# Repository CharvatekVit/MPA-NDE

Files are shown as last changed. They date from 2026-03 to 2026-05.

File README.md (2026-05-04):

# Jet ADCS with Siphon Cartridge

Experimental Attitude Determination and Control System (ADCS) for CubeSats using a reaction-based pneumatic propulsion system (RPPS).

---

Team members

1. Vít Charvátek (responsible for Pneumatics)
2. Vít Janoš (responsible for Electronics)
4. Antonín Putala (responsible for Software, Structure)

> [!WARNING]
> May 5 will be final presentation.

## 1. Project Overview
The **Jet ADCS with Siphon Cartridge** is an engineering project focused on the design and implementation of a single-axis orientation control system for nanosatellites (CubeSats). While traditional CubeSats rely on reaction wheels or magnetorquers, this project explores the use of compressed air to generate torque.

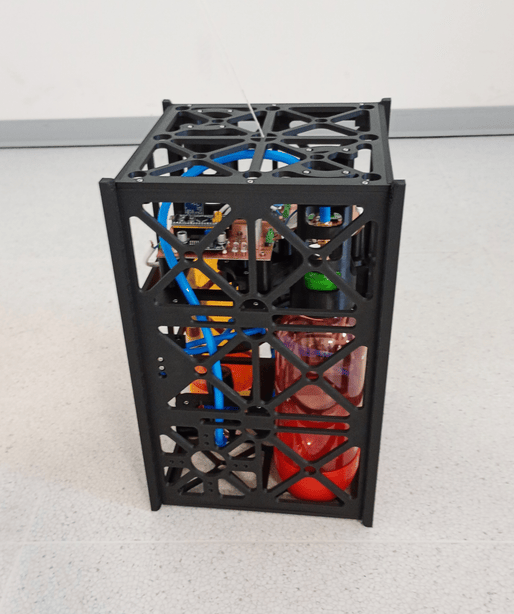
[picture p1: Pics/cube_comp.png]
Finished cube
 

### Core Concept
The system uses a compressed air as a propellant source. By regulating the pressure and precisely timing the opening of solenoid valves, the system can produce controlled thrust through two nozzles. This thrust creates a mechanical moment that allows the satellite to rotate to a desired angular position or maintain stability.

## Requirements
1.	Operation on battery supply
2.	Wireless control capability
2.  Attitude determination using an onboard sensor
2.  Actuation using compressed air
2.	Analysis of the pulse response of the system
2.  Maintaining a stable orientation around a single axis
2.	Performing controlled orientation changes

### Conceptual Scheme
The operational logic follows this flow:
1. **Sensing:** The IMU tracks the current orientation and angular velocity.
2. **Processing:** The STM32 microcontroller calculates the error between the desired and current state via a PID algorithm.
3. **Actuation:** Solenoid valves release precise bursts of air through nozzles to correct the orientation.
4. **Monitoring:** Data is sent wirelessly via Bluetooth to a ground station for real-time analysis.

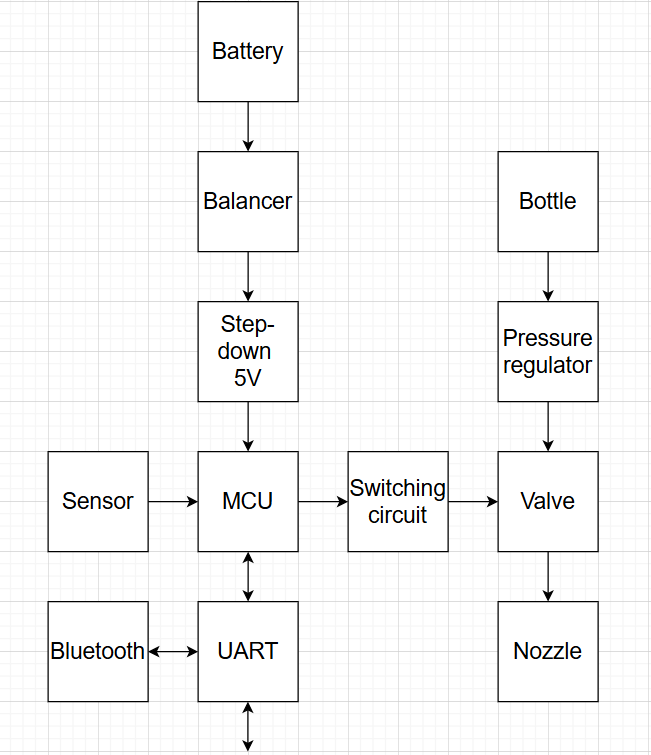
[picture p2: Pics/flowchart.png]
Conceptual diagram


---

## 2. Electronics
The electronics subsystem provides the "intelligence" and power management for the device.
* **Control Unit:** STM32 "Blue Pill" (ARM Cortex-M3) managing high-speed PID loops and valve timing.
* **Sensors:** MPU9250 (9-axis IMU) providing high-precision data via SPI.
* **Communication:** HC-05 Bluetooth module for wireless telemetry and command uplink.
* **Power:** 3x Li-ion 18650 cells with an integrated BMS (Battery Management System) and a DC/DC converter for a stable 5V rail.

---

## 3. Pneumatics
The propulsion system is designed for reliability and simplicity under terrestrial testing conditions.
* **Propellant:** Standard SodaStream bottle with compressed air.
* **Regulation:** AR2000 pressure regulator to step down high cartridge pressure to a constant operational level.
* **Actuators:** Two 2V025-08 electromagnetic solenoid valves.

---

## 4. Structure
The mechanical frame follows the CubeSat form factor philosophy, optimized for a single-axis testbed.
* **Frame:** 12U-inspired vertical structure manufactured using PETG filament on a 3D printer.
* **Assembly:** Secured with M2.5 threaded heat-set inserts for high durability and repeatable maintenance.
* **Balancing:** Adjustable mounts for internal components to align the center of mass with the rotation axis.

---

## 5. Software
The firmware is written in C, focusing on low latency and deterministic control.
* **Control Loop:** An easy function enables perform motion commands.
* **Data Fusion:** Processing of gyroscope data from the MPU9250.
* **Interface:** Custom serial protocol over Bluetooth for real-time controlling and state monitoring.

---

## Task list
- [x] System
   * [x] Conceptual diagram
   * [x] Requirements
   * [x] Energy budget
   * [x] Component list
   * [x] Component purchase
   * [x] Physical description
   * [x] Report
- [x]  Electronics
   * [x] Component choice 
      - [x] Battery
      - [x] Step-down
      - [x] Accelerometer
   * [x] Circuit design
      - [x] LED indicator
      - [x] Switching circuit
   * [x] PCB design
   * [x] Soldering
- [x]  Pneumatics
   * [x] Component choice 
      - [x] Valve
      - [x] T-hub
      - [x] Tube
   * [x]  Gas bottle construction
   * [x]  Completation pneumatic circuit
   * [x]  Sealing
   * [x]  Nozzles
- [x] Software
   * [x] Component choice 
       - [x] MCU
       - [x] Wireless module
   * [x] UART communication
       - [x] Sensor data
       - [x] Valve control
           * [x] Position setting
           * [x] Position regulation
       - [x] Command implementation
   * [x] Wireless communication
   * [x] Constant tuning
   * [x] Testing
   * [x] Doxygen
- [x] Structure
   * [x] Size estimation
   * [x] Structural design
   * [x] 3D print
   * [x] Assembly
     
---

## Documents
- [Part list](https://vutbr-my.sharepoint.com/:x:/r/personal/246858_vutbr_cz/Documents/MPA-NDE%20Part%20List.xlsx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)
- [Presentation 1](https://vutbr-my.sharepoint.com/:p:/r/personal/246850_vutbr_cz/_layouts/15/Doc.aspx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)
- [Presentation 2](https://vutbr-my.sharepoint.com/:p:/r/personal/246922_vutbr_cz/_layouts/15/Doc.aspx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)
- [Presentation 3](https://vutbr-my.sharepoint.com/:p:/r/personal/246922_vutbr_cz/_layouts/15/Doc.aspx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)
- [Presentation 4](https://vutbr-my.sharepoint.com/:p:/r/personal/246922_vutbr_cz/_layouts/15/Doc.aspx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)
- [Presentation 5](https://vutbr-my.sharepoint.com/:p:/r/personal/246922_vutbr_cz/_layouts/15/Doc.aspx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)
- [Presentation final](https://vutbr-my.sharepoint.com/:p:/r/personal/246922_vutbr_cz/_layouts/15/Doc.aspx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)
- [Programming documantation](https://raw.githack.com/CharvatekVit/MPA-NDE/main/Documentation/html/index.html)
- [Documentation](https://vutbr-my.sharepoint.com/:f:/g/personal/246922_vutbr_cz/IgBKQASchL7PSJfr07Y2DRViAZgop-J1y6nprSuAsayNgWo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)

## 6. Bibliography

[1] HALLIDAY, David; RESNICK, Robert and JEARL WALKER. Fundamentals of physics, 
New York: John Wiley, 1986.
ISBN: 9780470148853.

[2] -, Mass Flow Choking. Online. 2026 NASA. [cit. 2026-04-09]. Available from: https://www.grc.nasa.gov/WWW/K-12/airplane/mflchk.html

[3] POVALAČ, A., Nanosatellite Design and Electronics, Brno: Brno University of Technology, 
Faculty of electrical engineering and communications, 2021.

[4] -, CubeSat Design Specification. Online. 2026 NASA. [cit. 2026-04-11]. Available from: https://www.nasa.gov/wp-content/uploads/2018/01/cubesatdesignspecificationrev14_12022-02-09.pdf

[5] -, Heat Set Inserts . Online. 2026 Prusa 3D. [cit. 2026-04-12]. Available from: https://www.prusa3d.com/product/threaded-inserts-m2-5-standard-100-pcs/

[6] -, Solenoid Valve Specifications and Dimensions: 2V025 & 2V035 Series . Online. 2026 STC valve. [cit. 2026-04-18]. Available from: https://www.stcvalve.com/Solenoid_Valve_Specification_2V025.htm

[7] -, Regulátor tlaku s manometrem 1/4 palce AR2000 . Online. 2026 HP Control. [cit. 2026-04-18]. Available from: https://hpcontrol.cz/reduktor-regulator-1-4-cala-manometr-ar2000.html

[8] -, mpu9250 . Online. 2026 Libdriver. [cit. 2026-04-23]. Available from: https://github.com/libdriver/mpu9250

[9] Khaled Magdy, STM32 Blue Pill Pinout & Programming Guide . Online. 2026 DeepBlue Embedded. [cit. 2026-04-26]. Available from: https://deepbluembedded.com/stm32-blue-pill-pinout-programming-guide/

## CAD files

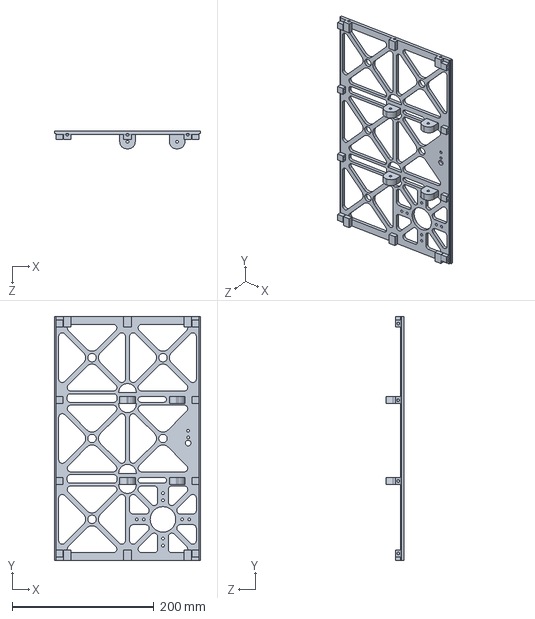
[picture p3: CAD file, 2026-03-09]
3D_model/My_side_full.SLDPRT
206.0 x 344.0 x 25.0 mm

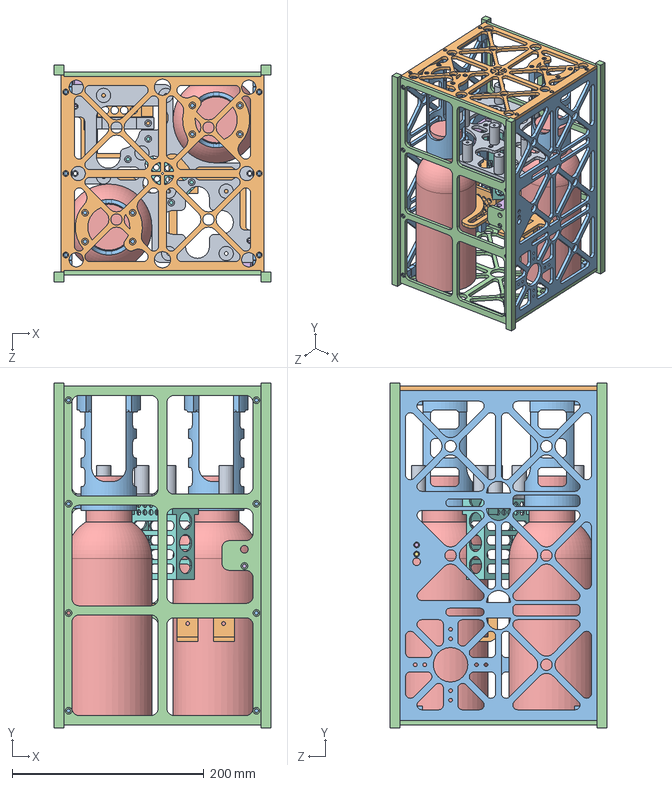
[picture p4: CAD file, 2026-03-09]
3D_model/Cube.SLDASM
226.3 x 360.0 x 226.3 mm
My_side_free x 2
My_side_full x 2
My_top
Mid_stage
Battery
Mid_tryska x 2
Top_tryska x 4
Láhev x 2
My_bottom
Drzak_lahev x 2
regulator_holder
Valve_holder

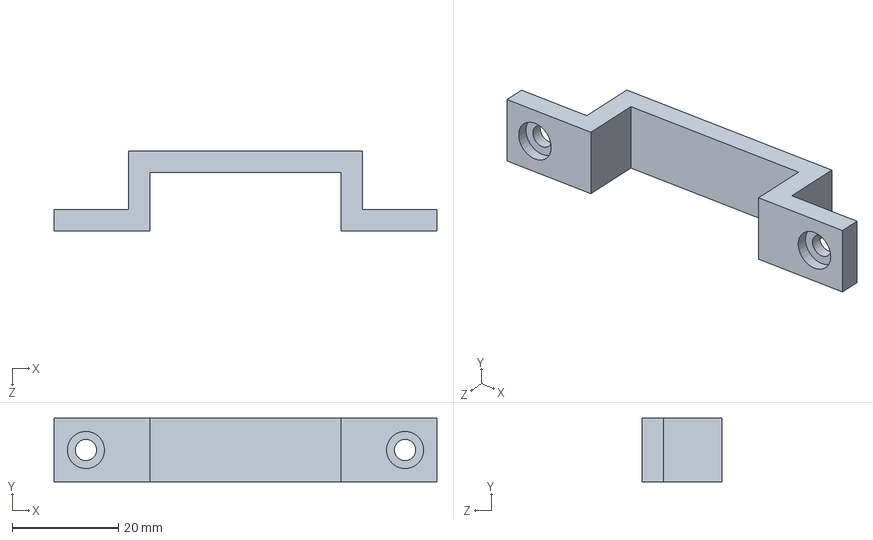
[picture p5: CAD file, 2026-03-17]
3D_model/Valve_holder.SLDPRT
72.0 x 12.0 x 15.0 mm

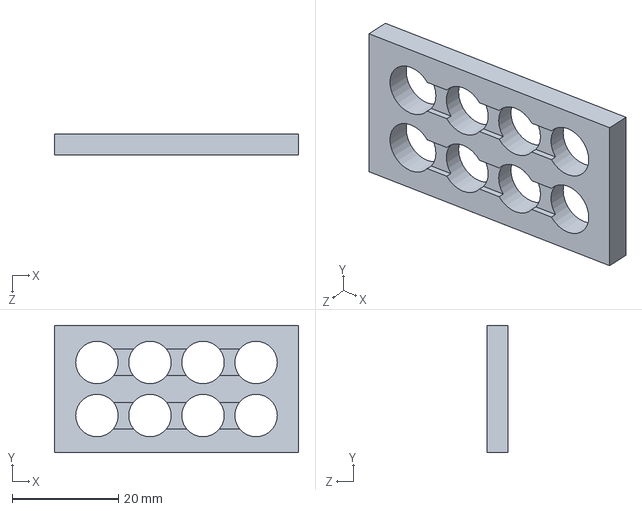
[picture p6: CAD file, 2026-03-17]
3D_model/podlozka.SLDPRT
46.0 x 24.0 x 4.00 mm

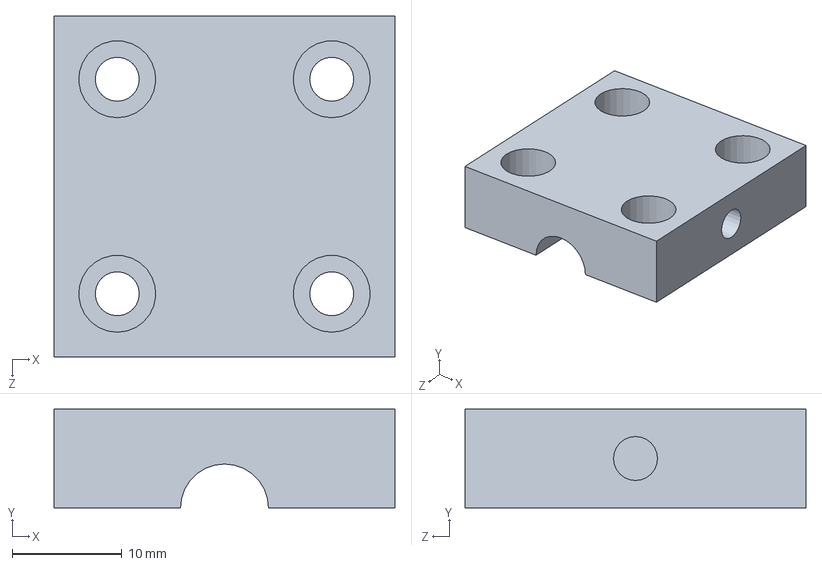
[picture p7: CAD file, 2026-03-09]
3D_model/Top_tryska.SLDPRT
31.0 x 9.00 x 31.0 mm

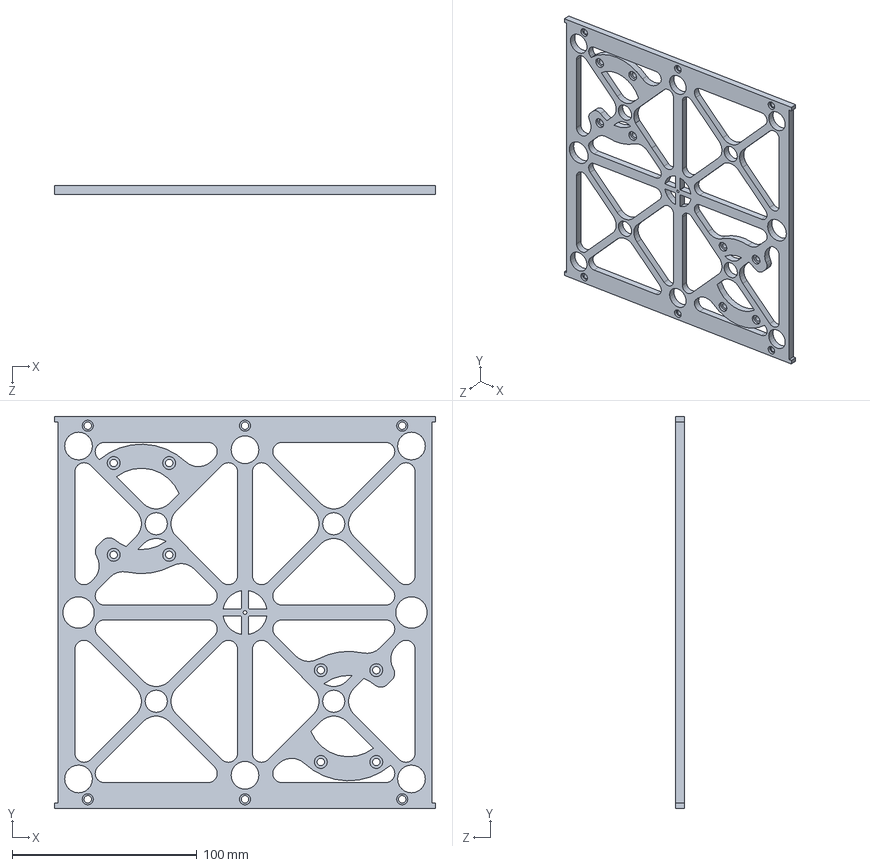
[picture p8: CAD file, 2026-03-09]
3D_model/My_top.SLDPRT
206.0 x 212.0 x 5.00 mm

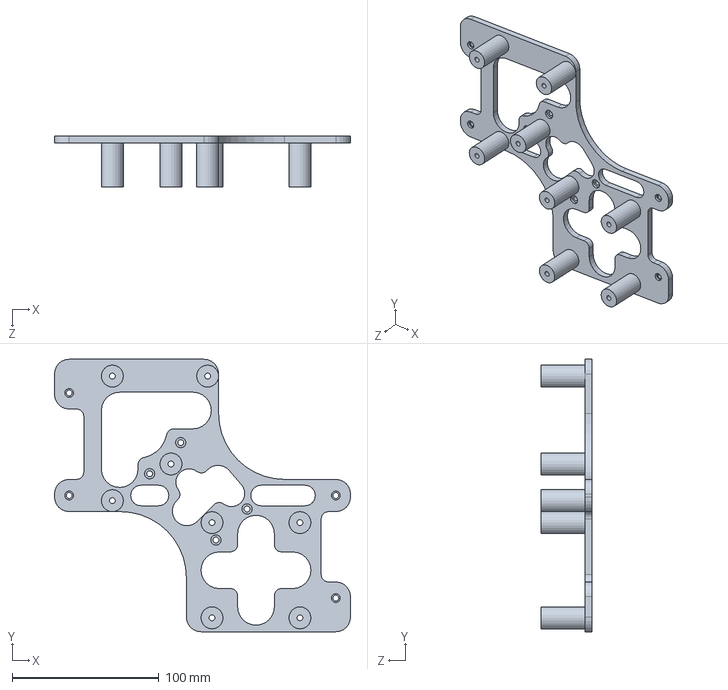
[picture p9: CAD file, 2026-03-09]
3D_model/Mid_stage.SLDPRT
202.0 x 186.0 x 35.0 mm

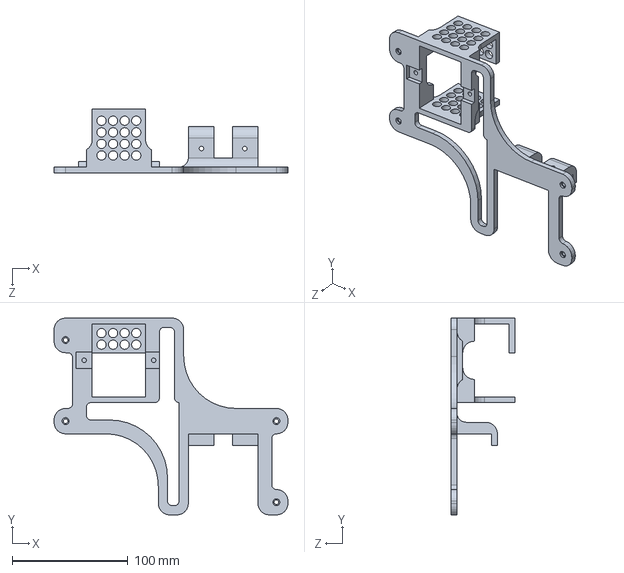
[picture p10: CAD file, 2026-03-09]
3D_model/regulator_holder.SLDPRT
202.0 x 170.0 x 55.0 mm

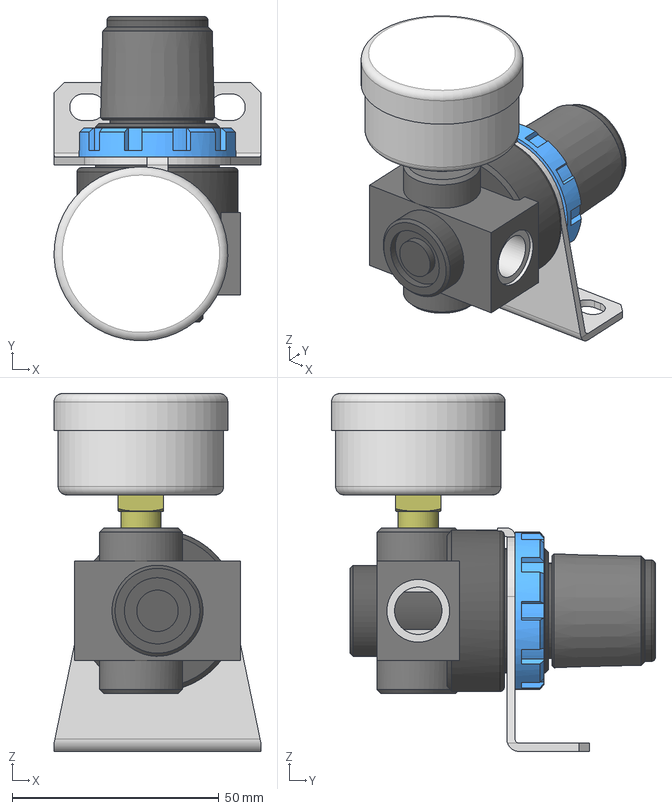
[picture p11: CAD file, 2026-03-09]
3D_model/AR2000.stp
50.0 x 78.3 x 86.5 mm
AR2000_AR
AFR2000ar_bracket
AR2000ar_nut
01gauge

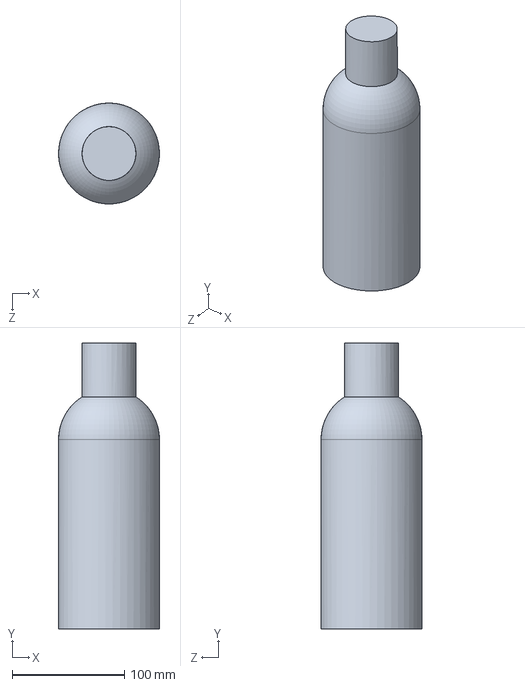
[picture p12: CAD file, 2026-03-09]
3D_model/Láhev.SLDPRT
90.0 x 255.0 x 90.0 mm

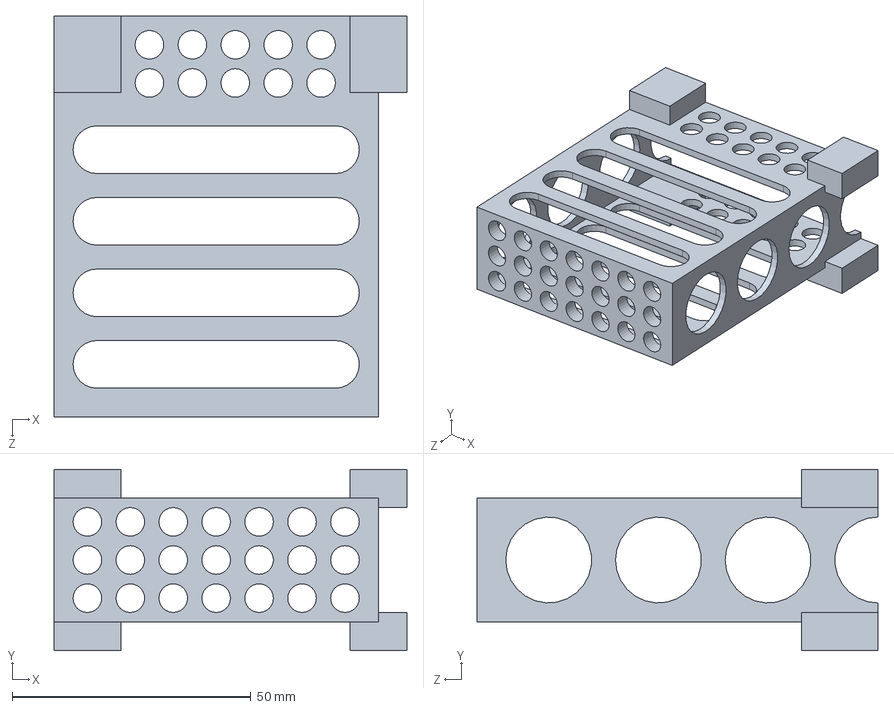
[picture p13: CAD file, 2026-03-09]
3D_model/Battery.SLDPRT
74.0 x 38.0 x 84.0 mm

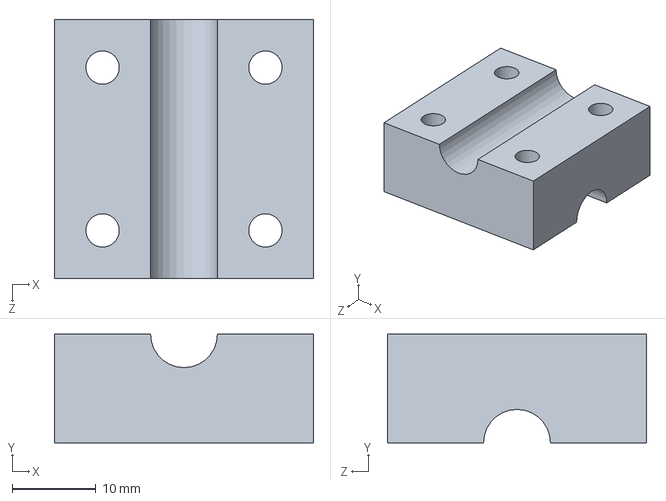
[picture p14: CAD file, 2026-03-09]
3D_model/Mid_tryska.SLDPRT
31.0 x 13.0 x 31.0 mm

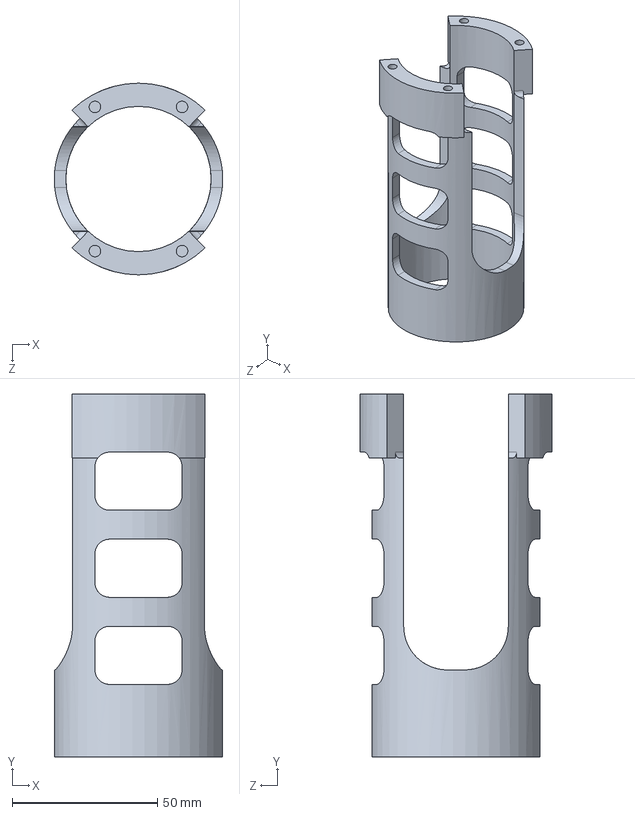
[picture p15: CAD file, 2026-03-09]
3D_model/Drzak_lahev.SLDPRT
58.0 x 125.0 x 66.0 mm

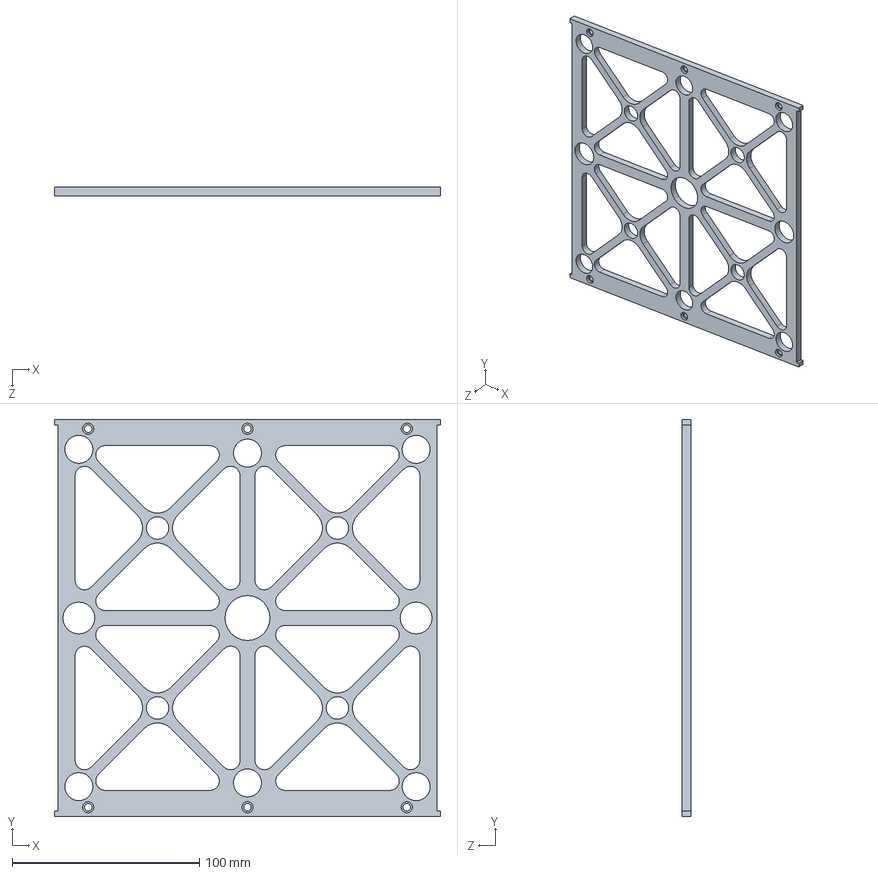
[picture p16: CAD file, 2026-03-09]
3D_model/My_bottom.SLDPRT
206.0 x 212.0 x 5.00 mm

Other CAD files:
3D_model/My_side_free.SLDPRT
3D_model/M25_10.SLDPRT

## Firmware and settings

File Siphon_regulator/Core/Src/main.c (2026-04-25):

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
/* Includes ------------------------------------------------------------------*/
#include "main.h"

/* USER CODE BEGIN Includes */
#include "cmd_processing.h"
#include "driver_mpu9250_basic.h"
#include "loop_fcn.h"
#include "sensor_fcn.h"
#include <stdio.h>
/* USER CODE END Includes */

/* USER CODE BEGIN PD */
/** Size of RX buffer for UART */
#define RX_BUFFER_LEN 64
/** Address of UART RX pointer */
#define uart_rx_write_ptr (RX_BUFFER_LEN - hdma_usart1_rx.Instance->CNDTR)

/* USER CODE END PD */

SPI_HandleTypeDef hspi2;

UART_HandleTypeDef huart1;
DMA_HandleTypeDef hdma_usart1_rx;

/* USER CODE BEGIN PV */
static uint8_t uart_rx_buf[RX_BUFFER_LEN];     ///< Received buffer fo UART
static volatile uint16_t uart_rx_read_ptr = 0; ///< Received read pointer for UART

sensor_data_t measured_data;                   ///< Current sensor measured data.
settings_t    set_data;                        ///< Main system settings.

/* USER CODE END PV */

void SystemClock_Config(void);
static void MX_GPIO_Init(void);
static void MX_DMA_Init(void);
static void MX_USART1_UART_Init(void);
static void MX_SPI2_Init(void);
/* USER CODE BEGIN PFP */

/**
 * @brief Set default values of set_data global variable.
 */
void setting_init(void);

/**
 * @brief Initialize valves. By default close.
 */
void valve_init(void);

/* USER CODE END PFP */

/* USER CODE BEGIN 0 */
int _write(int file, char const *buf, int n)
{
	/* stdout redirection to UART2 */
	HAL_UART_Transmit(&huart1, (uint8_t*)(buf), n, HAL_MAX_DELAY);
	return n;
}


void setting_init(void)
{
	/* Default data */
	set_data.angle  = 90; ///< 90 deg
	set_data.time_a = 10; ///< 10 * 0.1 = 1 sec
	set_data.time_l = 20; ///< 20 * 10 = 200 us
	set_data.time_r = 20; ///< 20 * 10 = 200 us
	set_data.home   =  0; ///< default orientation
}

void valve_init(void)
{
	/* Valves are closed by default */
	HAL_GPIO_WritePin(VALVE_L_GPIO_Port, VALVE_L_Pin, 0);
	HAL_GPIO_WritePin(VALVE_R_GPIO_Port, VALVE_R_Pin, 0);
}
/* USER CODE END 0 */

/**
 * @brief  The application entry point.
 * @retval int
 */
int main(void)
{

	/* USER CODE BEGIN 1 */
	uint32_t cmd_reg = 0;
	float set_position = 0;
	float gyr_offset[3];

	setting_init();
	valve_init();
	/* USER CODE END 1 */

	/* MCU Configuration--------------------------------------------------------*/

	/* Reset of all peripherals, Initializes the Flash interface and the Systick. */
	HAL_Init();

	/* Configure the system clock */
	SystemClock_Config();

	/* Initialize all configured peripherals */
	MX_GPIO_Init();
	MX_DMA_Init();
	MX_USART1_UART_Init();
	MX_SPI2_Init();
	/* USER CODE BEGIN 2 */
	HAL_UART_Receive_DMA(&huart1, uart_rx_buf, RX_BUFFER_LEN);

	sensor_init(gyr_offset);

	/* USER CODE END 2 */

	/* Infinite loop */
	/* USER CODE BEGIN WHILE */
	while (1)
	{
		while (uart_rx_read_ptr != uart_rx_write_ptr)
		{
			uint8_t b = uart_rx_buf[uart_rx_read_ptr];
			/* increase read pointer */
			if (++uart_rx_read_ptr >= RX_BUFFER_LEN)
			{
				uart_rx_read_ptr = 0;
			}
			/* process every received byte with the RX state machine */
			uart_byte_available(b, &cmd_reg);

		}

		autoread_fcn(cmd_reg);
		valve_fcn(&cmd_reg, &set_position);
		regul_fcn(&cmd_reg, set_position);
		sensor_get_value(gyr_offset);

		/* USER CODE END WHILE */

		/* USER CODE BEGIN 3 */
	}
	/* USER CODE END 3 */
}

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


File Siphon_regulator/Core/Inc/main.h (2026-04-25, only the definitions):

#define BOARD_LED_Pin GPIO_PIN_13
#define BOARD_LED_GPIO_Port GPIOC
#define VALVE_R_Pin GPIO_PIN_2
#define VALVE_R_GPIO_Port GPIOA
#define VALVE_L_Pin GPIO_PIN_3
#define VALVE_L_GPIO_Port GPIOA
#define LED_R_Pin GPIO_PIN_5
#define LED_R_GPIO_Port GPIOA
#define LED_Y_Pin GPIO_PIN_6
#define LED_Y_GPIO_Port GPIOA
#define LED_G_Pin GPIO_PIN_7
#define LED_G_GPIO_Port GPIOA
#define SPI2_CS_Pin GPIO_PIN_9
#define SPI2_CS_GPIO_Port GPIOB
#define RUN_BIT           0
#define DIR_BIT           1
#define PULSE_BIT         2
#define TURN_BIT          3
#define REG_BIT           4
#define RETURN_BIT        5
#define HOME_BIT          7
#define AUTOREAD_BIT     24
#define AUTOREAD_ACC_BIT 25
#define AUTOREAD_GYR_BIT 26
#define AUTOREAD_POS_BIT 27
#define PULSE_REPRE      10 //
#define CAL_MUL     ((360.0f/328.0f)*(360.0f/349.0f))
#define CMD0_BIT         28
#define CMD1_BIT         29
#define CMD2_BIT         30
#define CMD3_BIT         31

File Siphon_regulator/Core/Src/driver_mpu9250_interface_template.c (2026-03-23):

/**
 * Copyright (c) 2015 - present LibDriver All rights reserved
 * 
 * The MIT License (MIT)
 *
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
 * @file      driver_mpu9250_interface_template.c
 * @brief     driver mpu9250 interface template source file
 * @version   1.0.0
 * @author    Shifeng Li
 * @date      2022-08-30
 *
 * <h3>history</h3>
 * <table>
 * <tr><th>Date        <th>Version  <th>Author      <th>Description
 * <tr><td>2022/08/30  <td>1.0      <td>Shifeng Li  <td>first upload
 * </table>
 */

/* Includes */
#include "driver_mpu9250_interface.h"

#include "stm32f1xx_hal.h"
#include "main.h"
#include <stdio.h>
#include <stdarg.h>

/* Defines */
#define MPU9250_CS_LOW()  HAL_GPIO_WritePin(SPI2_CS_GPIO_Port, SPI2_CS_Pin, 0)
#define MPU9250_CS_HIGH() HAL_GPIO_WritePin(SPI2_CS_GPIO_Port, SPI2_CS_Pin, 1)

/* Extern global variables */
extern SPI_HandleTypeDef hspi2;

/**
 * @brief  interface iic bus init
 * @return status code
 *         - 0 success
 *         - 1 iic init failed
 * @note   none
 */
uint8_t mpu9250_interface_iic_init(void)
{
	return 0;
}

/**
 * @brief  interface iic bus deinit
 * @return status code
 *         - 0 success
 *         - 1 iic deinit failed
 * @note   none
 */
uint8_t mpu9250_interface_iic_deinit(void)
{
	return 0;
}

/**
 * @brief      interface iic bus read
 * @param[in]  addr iic device write address
 * @param[in]  reg iic register address
 * @param[out] *buf pointer to a data buffer
 * @param[in]  len length of the data buffer
 * @return     status code
 *             - 0 success
 *             - 1 read failed
 * @note       none
 */
uint8_t mpu9250_interface_iic_read(uint8_t addr, uint8_t reg, uint8_t *buf, uint16_t len)
{
	return 0;
}

/**
 * @brief     interface iic bus write
 * @param[in] addr iic device write address
 * @param[in] reg iic register address
 * @param[in] *buf pointer to a data buffer
 * @param[in] len length of the data buffer
 * @return    status code
 *            - 0 success
 *            - 1 write failed
 * @note      none
 */
uint8_t mpu9250_interface_iic_write(uint8_t addr, uint8_t reg, uint8_t *buf, uint16_t len)
{
	return 0;
}

/**
 * @brief  interface spi bus init
 * @return status code
 *         - 0 success
 *         - 1 spi init failed
 * @note   none
 */
uint8_t mpu9250_interface_spi_init(void)
{
	/* SPI is inicialized in main.c. Here only setting CS pin. */
	MPU9250_CS_HIGH();
	return 0;
}

/**
 * @brief  interface spi bus deinit
 * @return status code
 *         - 0 success
 *         - 1 spi deinit failed
 * @note   none
 */
uint8_t mpu9250_interface_spi_deinit(void)
{   
	return 0;
}

/**
 * @brief      interface spi bus read
 * @param[in]  reg register address
 * @param[out] *buf pointer to a data buffer
 * @param[in]  len length of data buffer
 * @return     status code
 *             - 0 success
 *             - 1 read failed
 * @note       none
 */
uint8_t mpu9250_interface_spi_read(uint8_t reg, uint8_t *buf, uint16_t len)
{
	/* MSB is set because I want to read */
	uint8_t tx_reg = reg | 0x80;

	MPU9250_CS_LOW();

	/* Send request */
	if (HAL_SPI_Transmit(&hspi2, &tx_reg, 1, 1000) != HAL_OK)
	{
		MPU9250_CS_HIGH();
		return 1;
	}

	/*  Read data */
	if (HAL_SPI_Receive(&hspi2, buf, len, 1000) != HAL_OK)
	{
		MPU9250_CS_HIGH();
		return 1;
	}

	MPU9250_CS_HIGH();
	return 0;
}

/**
 * @brief     interface spi bus write
 * @param[in] reg register address
 * @param[in] *buf pointer to a data buffer
 * @param[in] len length of data buffer
 * @return    status code
 *            - 0 success
 *            - 1 write failed
 * @note      none
 */
uint8_t mpu9250_interface_spi_write(uint8_t reg, uint8_t *buf, uint16_t len)
{
	/* MSB is clear because I want to write */
	    uint8_t tx_reg = reg & 0x7F;

	    MPU9250_CS_LOW();

	    /* Send address selected register */
	    if (HAL_SPI_Transmit(&hspi2, &tx_reg, 1, 1000) != HAL_OK)
	    {
	        MPU9250_CS_HIGH();
	        return 1;
	    }

	    /* Input data to selected register */
	    if (HAL_SPI_Transmit(&hspi2, buf, len, 1000) != HAL_OK)
	    {
	        MPU9250_CS_HIGH();
	        return 1;
	    }

	    MPU9250_CS_HIGH();
	    return 0;
}

/**
 * @brief     interface delay ms
 * @param[in] ms time
 * @note      none
 */
void mpu9250_interface_delay_ms(uint32_t ms)
{
	HAL_Delay(ms);
}

/**
 * @brief     interface print format data
 * @param[in] fmt format data
 * @note      none
 */
void mpu9250_interface_debug_print(const char *const fmt, ...)
{
	va_list args;

	/* Process printf with variable number of arguments */
	va_start(args, fmt);
	vprintf(fmt, args);
	va_end(args);
}

/**
 * @brief     interface receive callback
 * @param[in] type irq type
 * @note      none
 */
void mpu9250_interface_receive_callback(uint8_t type)
{
	switch (type)
	{
	case MPU9250_INTERRUPT_MOTION :
	{
		mpu9250_interface_debug_print("mpu9250: irq motion.\n");

		break;
	}
	case MPU9250_INTERRUPT_FIFO_OVERFLOW :
	{
		mpu9250_interface_debug_print("mpu9250: irq fifo overflow.\n");

		break;
	}
	case MPU9250_INTERRUPT_FSYNC_INT :
	{
		mpu9250_interface_debug_print("mpu9250: irq fsync int.\n");

		break;
	}
	case MPU9250_INTERRUPT_DMP :
	{
		mpu9250_interface_debug_print("mpu9250: irq dmp\n");

		break;
	}
	case MPU9250_INTERRUPT_DATA_READY :
	{
		mpu9250_interface_debug_print("mpu9250: irq data ready\n");

		break;
	}
	default :
	{
		mpu9250_interface_debug_print("mpu9250: irq unknown code.\n");

		break;
	}
	}
}

/**
 * @brief     interface dmp tap callback
 * @param[in] count tap count
 * @param[in] direction tap direction
 * @note      none
 */
void mpu9250_interface_dmp_tap_callback(uint8_t count, uint8_t direction)
{
	switch (direction)
	{
	case MPU9250_DMP_TAP_X_UP :
	{
		mpu9250_interface_debug_print("mpu9250: tap irq x up with %d.\n", count);

		break;
	}
	case MPU9250_DMP_TAP_X_DOWN :
	{
		mpu9250_interface_debug_print("mpu9250: tap irq x down with %d.\n", count);

		break;
	}
	case MPU9250_DMP_TAP_Y_UP :
	{
		mpu9250_interface_debug_print("mpu9250: tap irq y up with %d.\n", count);

		break;
	}
	case MPU9250_DMP_TAP_Y_DOWN :
	{
		mpu9250_interface_debug_print("mpu9250: tap irq y down with %d.\n", count);

		break;
	}
	case MPU9250_DMP_TAP_Z_UP :
	{
		mpu9250_interface_debug_print("mpu9250: tap irq z up with %d.\n", count);

		break;
	}
	case MPU9250_DMP_TAP_Z_DOWN :
	{
		mpu9250_interface_debug_print("mpu9250: tap irq z down with %d.\n", count);

		break;
	}
	default :
	{
		mpu9250_interface_debug_print("mpu9250: tap irq unknown code.\n");

		break;
	}
	}
}
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

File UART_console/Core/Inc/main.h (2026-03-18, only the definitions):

#define MCO_Pin GPIO_PIN_0
#define MCO_GPIO_Port GPIOF
#define LED_GREEN_Pin GPIO_PIN_5
#define LED_GREEN_GPIO_Port GPIOA
#define TMS_Pin GPIO_PIN_13
#define TMS_GPIO_Port GPIOA
#define TCK_Pin GPIO_PIN_14
#define TCK_GPIO_Port GPIOA
#define VALVE_R_Pin GPIO_PIN_4
#define VALVE_R_GPIO_Port GPIOB
#define VALVE_L_Pin GPIO_PIN_5
#define VALVE_L_GPIO_Port GPIOB
#define RUN_BIT           0 // movement was required
#define DIR_BIT           1 // 0 - left, 1 - right
#define PULSE_BIT         2 // only one pulse
#define TURN_BIT          3 // change attitude, 2 pulses
#define REG_BIT           4 // active if regulation is performed
#define HOME_BIT          7 // return to home position
#define AUTOREAD_BIT     24 // periodic sending messages through serial
#define AUTOREAD_ACC_BIT 25 // autoread includes accelerometer data
#define AUTOREAD_GYR_BIT 26 // autoread includes gyroscope data
#define AUTOREAD_MAG_BIT 27 // autoread includes magnetometer data
#define CMD0_BIT         28
#define CMD1_BIT         29
#define CMD2_BIT         30
#define CMD3_BIT         31

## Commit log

2026-02-17 Add component list
    [Component_list.xlsx]
2026-02-17 Remove component list
    [Component_list.xlsx]
2026-02-20 Add soldering and command implementation tasks
2026-03-07 Software update:
    UART_console:
    communication interface for bluetooth modul
    cmd: hello, read and turn was prepered
    communication tested
2026-03-08 UART console: Pulse cmd was added. enables set pulse in defined limits.
    Callbacks are included
    in library cmd_processing.
2026-03-08 UART console add reserve commands
2026-03-09 3D model: Add solidworks model with U12 cube
    [AR2000.stp, Battery.SLDPRT, Cube.SLDASM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]
2026-03-09 UART_console:
    add cmd_reg
    changes of bits run, turn, pulse, dir
    and cmd0:3 was inplemented in cmd_processing.c
2026-03-10 UART console
    returned value was replaced by pointer
    [cmd_processing.c, main.c]
2026-03-10 UART console
    add time to the cmd reg
2026-03-10 UART console
    Add home bit
2026-03-10 UART console
    add turning on/off
    autoreport setting
    gyr, acc, mag
2026-03-10 UART console
    enables put pulse cmd
    without time
2026-03-11 UART console
    autoread is working
    after each 1sec send
    data from selected sensors.
2026-03-12 UART console
    settings autoread time, valve time and
    turn angle was added
    functionality was tested
2026-03-12 UART console
    autoread func was placed
    to own library
    function was tested
2026-03-13 UART console
    set home was tested
2026-03-13 UART console reading of home position was deleted
2026-03-13 UART console
    removing test sensor data
2026-03-13 UART console
    pulse control was implemented
    tested with 1000 longer time
2026-03-13 UART console
    remove 1000 times longer time
2026-03-14 UART console
    turn cmd was implemented
    in loop_fnc
2026-03-14 UART console
    remove sending cmd reg
    add blocking turn, home and pulse
    command during processing another
2026-03-14 UART console
    valve controling was implemented
    to pins.
    Tested using scope.
2026-03-14 UART console
    ADD reset cmd
    [cmd_processing.c, loop_fcn.c]
2026-03-14 UART console
    preper callbach home cmd
2026-03-14 UART console
    remove debug msg
2026-03-17 Update README with project status changes
    Removed warning about the progress presentation and updated the status of wireless communication to completed.
2026-03-17 Update PCB design status to completed
2026-03-18 UART console
    add regul_fcn
    function is prepered for
    implementation of position
    regulation
2026-03-18 UART console
    add independent time
    for left and right valve
    detail test suitable
2026-03-18 UART console
    remove debug msges
2026-03-22 MPU9250 demo
    test SPI communication
2026-03-22 MPU9520
    create loop with reading measured data
    magnetometer do not work
    [main.c]
2026-03-22 MPU9250_demo
    magnetometer is working properly
2026-03-23 Hello world
    BluePill demo
    blinking of led on BluePill
2026-03-23 Siphon_regulator
    uart console is working properly
2026-03-23 Siphon regulator
    implemented reading from sensor
    to project
    data are included in global variable
    measured data
    blocked magnetometer sending to serial
2026-03-23 Siphon regulator
    remove useless comments
2026-03-23 Siphon regulator
    add library sensor fcn
    for handle with sensor
2026-03-24 Siphon regulator
    calibration included for gyroscope
2026-03-24 Siphon regulator
    remove debug msg and
    useless comments
2026-03-24 Siphon regulator
    change position of UART
    and valve pins
2026-03-24 Siphon regulator
    calculate relative position
2026-03-24 Siphon regulator
    add degree format of data
    add magic calibration constant
2026-03-24 Update UART communication checklist to mark sensor data as complete
2026-03-28 Siphon_regulator
    time fly replace angle condition
    [loop_fcn.c, sensor_fcn.c]
2026-04-09 Siphon progress
    add calibration constant for position
2026-04-11 Siphon progress
    add doxygen for reset cmd
    [cmd_processing.c, cmd_processing_def.h]
2026-04-11 Mark soldering task as completed in README
2026-04-20 Calibrate orientation measurement normal disable regulation
2026-04-20 Enables save to the valves data from 100ms to 1sec
2026-04-20 Change representation valve time is multiplied by 10
2026-04-24 Add doxygen to sensor fcn
2026-04-25 Complete doxygen for sensor_fcn
2026-04-25 Correct loop_fcn comments remove debug msg
    [loop_fcn.c]
2026-04-25 Add doxygen to loop fcn valve fcn

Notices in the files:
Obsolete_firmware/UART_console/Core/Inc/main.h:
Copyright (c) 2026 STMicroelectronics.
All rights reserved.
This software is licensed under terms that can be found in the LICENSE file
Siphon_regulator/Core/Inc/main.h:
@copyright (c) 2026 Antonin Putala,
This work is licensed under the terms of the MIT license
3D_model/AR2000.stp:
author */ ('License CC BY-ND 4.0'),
